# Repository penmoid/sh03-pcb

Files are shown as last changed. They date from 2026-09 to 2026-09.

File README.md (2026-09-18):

# SH03 controller

SH03 controller is an ESP32-S3-DevKitC-1 carrier board for the Sovol SH03
filament dryer. The board is a two-layer, 100 × 56 mm design. It carries nine
back-side SMD references: J1, J2, R1-R4, and C1-C3. J3 and the DevKitC-1
headers are through-hole parts fitted by the builder.

This repository contains the KiCad source, custom footprints, schematic
exports, fabrication files, renders, validation reports, and regeneration
scripts. The current design is Rev-A.

## Validation status

The repository documents CAD, DRC/ERC, routing, placement, and fabrication
checks. The project author has personally validated correct operation of the
assembled Rev-A board in the dryer. Perform the checks in
[docs/bring-up.md](docs/bring-up.md) before connecting a board to a dryer.

No firmware is included. The GPIO assignments are documented in
[docs/gpio-remap.md](docs/gpio-remap.md).

## Fabrication

The upload package is in [fab/](fab/). Read [fab/README.md](fab/README.md)
before ordering. The package contains Gerbers, a BOM, a CPL, and a STEP
export.

The BOM and sourcing notes are in [docs/bom.md](docs/bom.md). Connector mate
compatibility and all order-time sourcing information require confirmation
before an order.

## Images

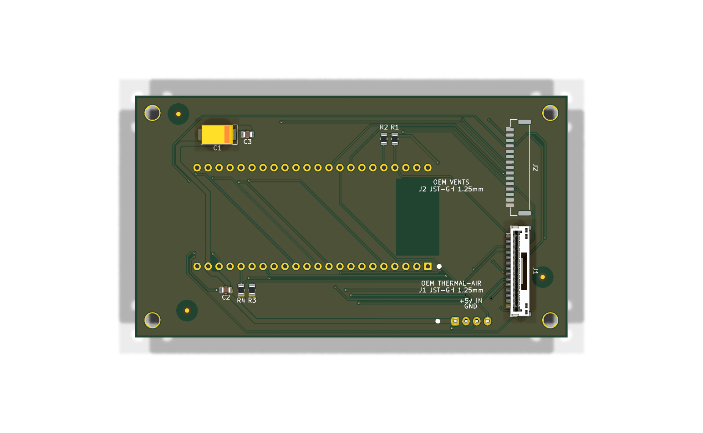
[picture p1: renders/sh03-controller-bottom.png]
Bottom render

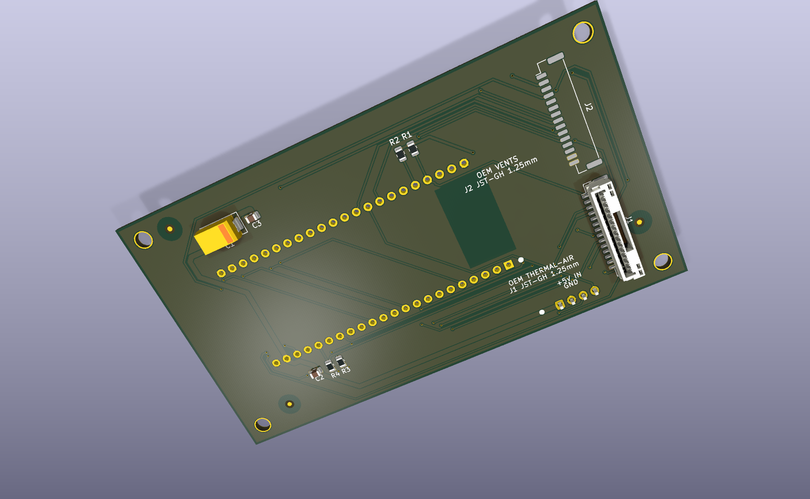
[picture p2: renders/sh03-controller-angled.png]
Angled render, J2 3D model unavailable


The angled render does not include a resolved J2 3D model.

## Toolchain

The source was generated and checked with KiCad 10.0.5. The scripts use the
standalone `pcbnew` Python module. The fab guide includes the `kicad-cli`
commands for Gerbers, drills, CPL, SVG, 3D renders, and schematic PDF export.

The board generation pipeline is documented in
[docs/layout-plan.md](docs/layout-plan.md):

```text
scripts/place_footprints.py
scripts/route_board.py
scripts/add_ground_pour.py
scripts/add_fiducials.py
```

Run `scripts/check_placement.py`, `scripts/report_pads.py`, and
`scripts/check_determinism.py` after regeneration.

## Licensing

Hardware and documentation are covered by [CERN-OHL-P-2.0](LICENSE).
Scripts are covered by [MIT](LICENSES/MIT.txt). See [NOTICE.md](NOTICE.md) for
third-party and KiCad-derived footprint exceptions.

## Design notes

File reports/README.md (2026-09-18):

# CAD validation

KiCad CLI 10.0.5 checked the unchanged Rev-A PCB and schematic on
2026-09-18. The project symbol library resolves through `${KIPRJMOD}`.

| Check | Errors | Warnings | Unconnected items |
|---|---:|---:|---:|
| DRC | 0 | 4 | 0 |
| ERC | 0 | 1 | Not applicable |

The four DRC warnings concern the local H1-H4 mounting-hole footprints, which
are absent from the configured `MountingHole` library. The ERC warning is a
U1 library-symbol mismatch: the embedded symbol hides pin numbers and uses
`~` for the datasheet field, while the library copy does not hide the numbers
and leaves that field empty. All 44 pin definitions match, including numbers,
names, electrical types, positions, and lengths.

The reports include all severities and no excluded violations. The existing
project configuration ignores these checks:

- DRC: missing courtyard, track endpoint not centered on via, tuning profile
  geometry, footprint filter mismatch, and footprint type mismatch.
- ERC: single-use global label, four-way junction, SPICE model issue, and
  footprint filter mismatch.

Run these commands from the project root with KiCad 10.0.5:

```sh
kicad-cli pcb drc --format json --severity-all -o reports/drc.json sh03-controller.kicad_pcb
kicad-cli sch erc --format json --severity-all -o reports/erc.json sh03-controller.kicad_sch
```

The Gerber outline matches the board at 100 × 56 mm. All nine BOM/CPL
references match the board, including placement coordinates and rotations
with the exported Y-axis sign convention. C1 pad 1 connects to +5V and pad 2
to GND.

These reports cover CAD checks. The project author has also personally validated
correct operation of the assembled Rev-A board in the dryer.

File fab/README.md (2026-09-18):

# Fabrication package

This directory contains the Rev-A order package generated from
`sh03-controller.kicad_pcb` with KiCad 10.0.5:

| File | Contents |
|---|---|
| `sh03-controller-gerbers.zip` | Gerbers, Excellon drill, and job file |
| `sh03-controller-cpl.csv` | Nine back-side SMD placements |
| `sh03-controller-bom.csv` | BOM covering nine SMD references |
| `sh03-controller.step` | Board and available 3D models |

The committed archive is the first-order package and remains unchanged for
reference. It uses a merged drill file. The fabrication house finished the
four mounting holes as plated 3.2 mm holes on that order. A future export should use
`--excellon-separate-th` and must be reviewed as a new package because that
flag changes the drill outputs.

## Assembly

All nine SMD references are on B.Cu: J1, J2, R1-R4, and C1-C3. J3 and U1's
2×22, 2.54 mm header arrangement are through-hole work. Direct soldering U1
is also supported.

Before ordering, confirm the JLCPCB Assembly Viewer orientation:

- J2, the 15-position vents connector, is in the north slot.
- J1, the 14-position thermal and air connector, is in the south slot.
- Both connectors are back-side placements with CPL rotation 270°.
- C1's positive stripe is on the +5V side.

The first order required a +180° correction in the Assembly Viewer for J1 and
J2. The correction was made in the viewer and was not silently applied to the
CPL. Review the native 270° CPL values and make any assembly-house correction
explicit during order review.

The committed STEP export does not contain a resolved J2 3D model. Use the
footprint and datasheet dimensions for J2 mechanical checks.

## Gerbers and drill

Run these commands from the project root. Create output directories first.

```text
mkdir -p build/gerbers

kicad-cli pcb export gerbers -o build/gerbers \
  -l F.Cu,B.Cu,F.SilkS,B.SilkS,F.Mask,B.Mask,F.Paste,B.Paste,Edge.Cuts \
  --no-x2 --no-netlist sh03-controller.kicad_pcb

kicad-cli pcb export drill -o build/gerbers/ --format excellon \
  --drill-origin absolute -u mm --excellon-zeros-format decimal \
  --generate-map --map-format gerberx2 sh03-controller.kicad_pcb
```

The merged drill export may cause the fabrication CAM process to treat NPTH
mounting holes as plated. Choose either the merged drill set or a separate
PTH/NPTH drill set for an upload. Never include both drill sets in one upload.
Use this command for a future separate export, then inspect the replacement
package:

```text
mkdir -p build/drill-separated

kicad-cli pcb export drill -o build/drill-separated/ --format excellon \
  --drill-origin absolute -u mm --excellon-zeros-format decimal \
  --excellon-separate-th --generate-map --map-format gerberx2 \
  sh03-controller.kicad_pcb
```

Generate a drill report when reviewing a package:

```text
kicad-cli pcb export drill -o build/gerbers/ --format excellon \
  --drill-origin absolute -u mm --excellon-zeros-format decimal \
  --generate-report --report-path build/gerbers/drill-report.txt \
  sh03-controller.kicad_pcb
```

The Gerber and CPL coordinate origin is the board file origin. Gerber and CPL
Y coordinates use the opposite sign from KiCad page coordinates.

## CPL

Export the placement list with:

```text
kicad-cli pcb export pos -o build/gerbers/sh03-controller-back-pos.csv \
  --side back --format csv --units mm sh03-controller.kicad_pcb
```

Filter the output to `J1`, `J2`, `R1`, `R2`, `R3`, `R4`, `C1`, `C2`, and `C3`.
Use the JLCPCB headers `Designator,Mid X,Mid Y,Layer,Rotation`, normalize
negative rotations into the 0 to 360 range, and keep all nine rows on the
bottom layer. Do not apply an undocumented connector rotation offset.

## SVG and 3D exports

These commands use the project root as the working directory. Run them with
KiCad 10.0.5 and the KiCad 3D model data available to the renderer.

```text
mkdir -p build/svg renders

kicad-cli pcb export svg -o build/svg/top-2d.svg \
  --layers F.Cu,F.SilkS,F.Mask,F.Paste,Edge.Cuts --page-size-mode 2 \
  --exclude-drawing-sheet --mode-single sh03-controller.kicad_pcb

kicad-cli pcb export svg -o build/svg/bottom-2d.svg \
  --layers B.Cu,B.SilkS,B.Mask,B.Paste,Edge.Cuts --page-size-mode 2 \
  --exclude-drawing-sheet --mode-single --mirror sh03-controller.kicad_pcb

kicad-cli pcb render -o renders/sh03-controller-top.png --side top \
  --width 1568 --height 984 --quality high --floor sh03-controller.kicad_pcb

kicad-cli pcb render -o renders/sh03-controller-bottom.png --side bottom \
  --width 1568 --height 984 --quality high --floor sh03-controller.kicad_pcb

kicad-cli pcb render -o renders/sh03-controller-angled.png --side bottom \
  --width 1568 --height 984 --quality high --perspective \
  --rotate 20,0,-25 --zoom 1.0 --background opaque sh03-controller.kicad_pcb

kicad-cli pcb render -o renders/sh03-controller-top-2d.png --side top \
  --width 1568 --height 984 --quality basic sh03-controller.kicad_pcb

kicad-cli pcb render -o renders/sh03-controller-bottom-2d.png --side bottom \
  --width 1568 --height 984 --quality basic sh03-controller.kicad_pcb
```

Export the schematic PDF separately:

```text
kicad-cli sch export pdf -o renders/sh03-controller-schematic.pdf \
  sh03-controller.kicad_sch
```

## Validation

The tracked reports record KiCad DRC and ERC runs. See
[`reports/README.md`](../reports/README.md). DRC reports 0 errors and 0
unconnected items with four mounting-hole library warnings. ERC reports one
U1 library-symbol warning. The 44 U1 pins are equivalent; the warning concerns
symbol display and metadata.

The project author has personally validated correct operation of the assembled
Rev-A board in the dryer.

Before releasing an order, inspect the Gerber viewer, drill map, BOM/CPL
reference alignment, C1 polarity, J1/J2 placement, and the J2 no-connect pin.

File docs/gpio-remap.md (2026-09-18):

# GPIO map

This table is the current PCB map. It includes the Hall ADC1 correction. Use
it for firmware written for the PCB.

| Signal | PCB GPIO | ADC or function |
|---|---:|---|
| TH2 | 1 | ADC1 |
| TH1 | 2 | ADC1 |
| MC_HOT2 | 11 | Digital |
| MC_HOT1 | 12 | Digital |
| MC_K_FAN3_FG | 38 | Tacho input |
| MC_K_FAN3 | 21 | Digital |
| MC_K_FAN2_FG | 48 | Tacho input |
| MC_K_FAN2 | 14 | Digital |
| MC_K_FAN1_FG | 47 | Tacho input |
| MC_K_FAN1 | 13 | Digital |
| MC_HUM_SDA | 8 | I2C |
| MC_HUM_SCL | 9 | I2C |
| MC_HALLA | 4 | ADC1_CH3 |
| MC_HALLB | 10 | ADC1_CH9 |
| MC_HALLC | 7 | ADC1_CH6 |
| MC_HALLD | 6 | ADC1_CH5 |
| MC_XQA1 | 41 | Digital |
| MC_XQA2 | 40 | Digital |
| MC_XQB1 | 3 | Digital, strapping pin |
| MC_XQB2 | 18 | Digital |
| MC_XQC1 | 15 | Digital |
| MC_XQC2 | 17 | Digital |
| MC_XQD1 | 5 | Digital |
| MC_XQD2 | 42 | Digital |
| MCU_TX | 16 | UART |
| MCU_RX | 39 | UART |

TH2 uses ADC1 GPIO1. TH1 uses ADC1 GPIO2. The UART is GPIO16/GPIO39. USB and
UART0 GPIO43/GPIO44 are unused by the board. The Hall sensors are ratiometric
analog inputs, so all four must stay on ADC1 GPIO1 through GPIO10 when WiFi is
active. GPIO11 through GPIO20 use ADC2 and are unsuitable for these inputs in
that condition. GPIO42 has no ADC channel.

## Perfboard to PCB changes

The current PCB changes these ten signal assignments from the earlier
perfboard wiring:

| Signal | Perfboard GPIO | PCB GPIO |
|---|---:|---:|
| MC_HALLB | 5 | 10 |
| MC_HALLC | 6 | 7 |
| MC_HALLD | 7 | 6 |
| MC_XQA1 | 17 | 41 |
| MC_XQA2 | 15 | 40 |
| MC_XQB1 | 10 | 3 |
| MC_XQC1 | 3 | 15 |
| MC_XQC2 | 40 | 17 |
| MC_XQD1 | 42 | 5 |
| MC_XQD2 | 41 | 42 |

MC_HALLA remains on GPIO4. MC_XQB2 remains on GPIO18. The TH, HOT, fan,
tacho, I2C, and UART assignments are listed in the authoritative table above.

## Firmware cutover

The repository contains no firmware. Keep the existing device on its old map
until the PCB has passed the bring-up checks and is ready for cutover. Apply
the current table only to firmware running with this PCB. A firmware update on
the earlier wiring changes the vent and Hall signals.

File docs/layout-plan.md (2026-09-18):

# Rev-A layout

This document describes the current board geometry and the constraints used by
the placement and routing scripts. Dimensions are millimetres.

## Enclosure and board

| Feature | Dimension or location |
|---|---|
| Enclosure cavity | 135.2 × 82.2 |
| Cable window | X 21.5 to 33.5, Y 15.5 to 66.7 |
| Board outline | 100 × 56, KiCad X 36 to 136 and Y 33 to 89 |
| Mounting holes | Four 3.2 mm finished holes, approximately 4 mm from board corners |

The board clears the enclosure bosses within the cavity Y band 10.5 to 71.6.
J1 and J2 sit in the cable window on the back side. J2 is the 15-position
connector in the north slot. J1 is the 14-position connector in the south slot.
Both connectors have pin 1 at the north end of their span.

## Placement

| Ref | Side | KiCad centre | Rotation | Function |
|---|---|---:|---:|---|
| J2 | B.Cu | (47.4, 49.625) | 270° | 15-position vents connector |
| J1 | B.Cu | (47.4, 73.625) | 270° | 14-position thermal and air connector |
| R1 | B.Cu | (75.95, 43.0) | 270° | TH2 33k pull-up |
| R2 | B.Cu | (78.49, 43.0) | 270° | TH1 33k pull-up |
| R3 | B.Cu | (108.97, 78.0) | 270° | MC_HOT2 10k pull-down |
| R4 | B.Cu | (111.51, 78.0) | 270° | MC_HOT1 10k pull-down |
| C1 | B.Cu | (117.0, 42.0) | 0° | 470 µF +5V bulk capacitor |
| C3 | B.Cu | (110.0, 42.0) | 0° | 10 µF +5V bypass |
| C2 | B.Cu | (115.0, 78.0) | 0° | 100 nF near J3 |
| U1 | F.Cu | (95.0, 61.1) | 90° | ESP32-S3-DevKitC-1 |
| J3 | F.Cu | (62.0, 85.2) | 180° | 4-position XH connector |

U1 is the height driver at about 7.2 mm above the PCB. J1 and J2 are about
4.25 mm high. C1 is about 4.3 mm high. Trim header tails flush after fitting
U1.

The four Hall signals use U1 GPIO4, GPIO6, GPIO7, and GPIO10. These are ADC1
inputs and remain usable while WiFi is active. See
[docs/gpio-remap.md](gpio-remap.md).

J2 pin 13 is no-connect by design. It isolates the driver-board 3V3 signal.
R3 and R4 provide the heater pull-downs and must be present.

## Reproduction

The source of truth for placement is the `PLACEMENT` dictionary in
`scripts/place_footprints.py`. The regeneration order is:

```text
mkdir -p build
kicad-cli sch export netlist --format kicadxml -o build/sh03.net \
  sh03-controller.kicad_sch
python3 scripts/place_footprints.py
python3 scripts/route_board.py
python3 scripts/add_ground_pour.py
python3 scripts/add_fiducials.py
```

Run these checks after regeneration:

```text
python3 scripts/check_placement.py
python3 scripts/report_pads.py
python3 scripts/check_determinism.py
```

`check_placement.py` checks courtyard overlap, board-edge clearance, requested
connector-hole clearances, and antenna keepout. `report_pads.py` reports the
connector and U1 pad mapping. `check_determinism.py` runs the pipeline twice
and compares the resulting board files.

The scripts use KiCad 10.0.5's standalone `pcbnew` Python module. They resolve
the project footprint libraries through the local library tables. Run the
pipeline on a disposable copy because the generation scripts overwrite the
board and generated pad reports.

For a Linux host with KiCad 10.0.5 installed, run the commands above from the
project root. To use the KiCad container, check the version and bind-mount the
project directory:

```text
docker run --rm -v "$PWD:/work" -w /work kicad/kicad:10.0 \
  kicad-cli --version
```

The current project was checked with KiCad 10.0.5. The container image may
resolve to a different 10.0 release, so confirm the version before generating
files. The base image does not provide every 3D model package. Install or
mount the KiCad 3D model data separately before rendering.

The fab guide contains the complete `kicad-cli` export commands. The committed
STEP export has no resolved J2 3D model. Treat its J2 visualization as
incomplete and check the physical part dimensions against the footprint.

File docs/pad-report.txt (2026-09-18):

ref    pin    net                     pad_x_mm  pad_y_mm  pad_w_mm  pad_h_mm shape      type layer   drill_mm
-------------------------------------------------------------------------------------------------------------
C1     1      /+5V                     113.793    42.000     2.245     2.590 roundrect  SMD  B.Cu            
C1     2      /GND                     120.207    42.000     2.245     2.590 roundrect  SMD  B.Cu            
C2     1      /+5V                     114.050    78.000     1.000     1.450 roundrect  SMD  B.Cu            
C2     2      /GND                     115.950    78.000     1.000     1.450 roundrect  SMD  B.Cu            
C3     1      /+5V                     109.050    42.000     1.000     1.450 roundrect  SMD  B.Cu            
C3     2      /GND                     110.950    42.000     1.000     1.450 roundrect  SMD  B.Cu            
H1            <no net>                  40.000    37.000     3.700     3.700 circle     TH   *          3.200
H2            <no net>                 128.000    37.000     3.700     3.700 circle     TH   *          3.200
H3            <no net>                  40.000    85.000     3.700     3.700 circle     TH   *          3.200
H4            <no net>                 128.000    85.000     3.700     3.700 circle     TH   *          3.200
J1     1      /TH2                      49.350    65.500     0.700     1.800 roundrect  SMD  B.Cu            
J1     2      /TH1                      49.350    66.750     0.700     1.800 roundrect  SMD  B.Cu            
J1     3      /MC_HOT2                  49.350    68.000     0.700     1.800 roundrect  SMD  B.Cu            
J1     4      /MC_HOT1                  49.350    69.250     0.700     1.800 roundrect  SMD  B.Cu            
J1     5      /MC_K_FAN3_FG             49.350    70.500     0.700     1.800 roundrect  SMD  B.Cu            
J1     6      /MC_K_FAN3                49.350    71.750     0.700     1.800 roundrect  SMD  B.Cu            
J1     7      /MC_K_FAN2_FG             49.350    73.000     0.700     1.800 roundrect  SMD  B.Cu            
J1     8      /MC_K_FAN2                49.350    74.250     0.700     1.800 roundrect  SMD  B.Cu            
J1     9      /MC_K_FAN1_FG             49.350    75.500     0.700     1.800 roundrect  SMD  B.Cu            
J1     10     /MC_K_FAN1                49.350    76.750     0.700     1.800 roundrect  SMD  B.Cu            
J1     11     /MC_HUM_SDA               49.350    78.000     0.700     1.800 roundrect  SMD  B.Cu            
J1     12     /MC_HUM_SCL               49.350    79.250     0.700     1.800 roundrect  SMD  B.Cu            
J1     13     /+5V                      49.350    80.500     0.700     1.800 roundrect  SMD  B.Cu            
J1     14     /GND                      49.350    81.750     0.700     1.800 roundrect  SMD  B.Cu            
J1     MP     <no net>                  45.930    63.660     1.020     2.940 roundrect  SMD  B.Cu            
J1     MP     <no net>                  45.930    83.590     1.020     2.940 roundrect  SMD  B.Cu            
J2     1      /MC_XQD2                  49.350    40.875     0.700     1.800 roundrect  SMD  B.Cu            
J2     2      /MC_XQD1                  49.350    42.125     0.700     1.800 roundrect  SMD  B.Cu            
J2     3      /MC_HALLD                 49.350    43.375     0.700     1.800 roundrect  SMD  B.Cu            
J2     4      /MC_XQC2                  49.350    44.625     0.700     1.800 roundrect  SMD  B.Cu            
J2     5      /MC_XQC1                  49.350    45.875     0.700     1.800 roundrect  SMD  B.Cu            
J2     6      /MC_HALLC                 49.350    47.125     0.700     1.800 roundrect  SMD  B.Cu            
J2     7      /MC_XQB2                  49.350    48.375     0.700     1.800 roundrect  SMD  B.Cu            
J2     8      /MC_XQB1                  49.350    49.625     0.700     1.800 roundrect  SMD  B.Cu            
J2     9      /MC_HALLB                 49.350    50.875     0.700     1.800 roundrect  SMD  B.Cu            
J2     10     /MC_XQA2                  49.350    52.125     0.700     1.800 roundrect  SMD  B.Cu            
J2     11     /MC_XQA1                  49.350    53.375     0.700     1.800 roundrect  SMD  B.Cu            
J2     12     /MC_HALLA                 49.350    54.625     0.700     1.800 roundrect  SMD  B.Cu            
J2     13     unconnected-(J2-Pin_13-Pad13)    49.350    55.875     0.700     1.800 roundrect  SMD  B.Cu            
J2     14     /GND                      49.350    57.125     0.700     1.800 roundrect  SMD  B.Cu            
J2     15     /GND                      49.350    58.375     0.700     1.800 roundrect  SMD  B.Cu            
J2     MP     <no net>                  45.930    39.035     1.020     2.940 roundrect  SMD  B.Cu            
J2     MP     <no net>                  45.930    60.215     1.020     2.940 roundrect  SMD  B.Cu            
J3     1      /+5V                      62.000    85.200     1.700     1.950 roundrect  TH   *          0.950
J3     2      /GND                      59.500    85.200     1.700     1.950 oval       TH   *          0.950
J3     3      /MCU_TX                   57.000    85.200     1.700     1.950 oval       TH   *          0.950
J3     4      /MCU_RX                   54.500    85.200     1.700     1.950 oval       TH   *          0.950
R1     1      /+3V3                     75.950    42.087     1.025     1.400 roundrect  SMD  B.Cu            
R1     2      /TH2                      75.950    43.913     1.025     1.400 roundrect  SMD  B.Cu            
R2     1      /+3V3                     78.490    42.087     1.025     1.400 roundrect  SMD  B.Cu            
R2     2      /TH1                      78.490    43.913     1.025     1.400 roundrect  SMD  B.Cu            
R3     1      /MC_HOT2                 108.970    77.088     1.025     1.400 roundrect  SMD  B.Cu            
R3     2      /GND                     108.970    78.912     1.025     1.400 roundrect  SMD  B.Cu            
R4     1      /MC_HOT1                 111.510    77.088     1.025     1.400 roundrect  SMD  B.Cu            
R4     2      /GND                     111.510    78.912     1.025     1.400 roundrect  SMD  B.Cu            
U1     1      /+3V3                     68.330    72.530     1.700     1.700 rect       TH   *          1.000
U1     2      /+3V3                     70.870    72.530     1.700     1.700 circle     TH   *          1.000
U1     3      unconnected-(U1-RST-Pad3)    73.410    72.530     1.700     1.700 circle     TH   *          1.000
U1     4      /MC_HALLA                 75.950    72.530     1.700     1.700 circle     TH   *          1.000
U1     5      /MC_XQD1                  78.490    72.530     1.700     1.700 circle     TH   *          1.000
U1     6      /MC_HALLD                 81.030    72.530     1.700     1.700 circle     TH   *          1.000
U1     7      /MC_HALLC                 83.570    72.530     1.700     1.700 circle     TH   *          1.000
U1     8      /MC_XQC1                  86.110    72.530     1.700     1.700 circle     TH   *          1.000
U1     9      /MCU_TX                   88.650    72.530     1.700     1.700 circle     TH   *          1.000
U1     10     /MC_XQC2                  91.190    72.530     1.700     1.700 circle     TH   *          1.000
U1     11     /MC_XQB2                  93.730    72.530     1.700     1.700 circle     TH   *          1.000
U1     12     /MC_HUM_SDA               96.270    72.530     1.700     1.700 circle     TH   *          1.000
U1     13     /MC_XQB1                  98.810    72.530     1.700     1.700 circle     TH   *          1.000
U1     14     unconnected-(U1-GPIO46-Pad14)   101.350    72.530     1.700     1.700 circle     TH   *          1.000
U1     15     /MC_HUM_SCL              103.890    72.530     1.700     1.700 circle     TH   *          1.000
U1     16     /MC_HALLB                106.430    72.530     1.700     1.700 circle     TH   *          1.000
U1     17     /MC_HOT2                 108.970    72.530     1.700     1.700 circle     TH   *          1.000
U1     18     /MC_HOT1                 111.510    72.530     1.700     1.700 circle     TH   *          1.000
U1     19     /MC_K_FAN1               114.050    72.530     1.700     1.700 circle     TH   *          1.000
U1     20     /MC_K_FAN2               116.590    72.530     1.700     1.700 circle     TH   *          1.000
U1     21     /+5V                     119.130    72.530     1.700     1.700 circle     TH   *          1.000
U1     22     /GND                     121.670    72.530     1.700     1.700 circle     TH   *          1.000
U1     23     /GND                      68.330    49.670     1.700     1.700 circle     TH   *          1.000
U1     24     unconnected-(U1-TX_GPIO43-Pad24)    70.870    49.670     1.700     1.700 circle     TH   *          1.000
U1     25     unconnected-(U1-RX_GPIO44-Pad25)    73.410    49.670     1.700     1.700 circle     TH   *          1.000
U1     26     /TH2                      75.950    49.670     1.700     1.700 circle     TH   *          1.000
U1     27     /TH1                      78.490    49.670     1.700     1.700 circle     TH   *          1.000
U1     28     /MC_XQD2                  81.030    49.670     1.700     1.700 circle     TH   *          1.000
U1     29     /MC_XQA1                  83.570    49.670     1.700     1.700 circle     TH   *          1.000
U1     30     /MC_XQA2                  86.110    49.670     1.700     1.700 circle     TH   *          1.000
U1     31     /MCU_RX                   88.650    49.670     1.700     1.700 circle     TH   *          1.000
U1     32     /MC_K_FAN3_FG             91.190    49.670     1.700     1.700 circle     TH   *          1.000
U1     33     unconnected-(U1-GPIO37-Pad33)    93.730    49.670     1.700     1.700 circle     TH   *          1.000
U1     34     unconnected-(U1-GPIO36-Pad34)    96.270    49.670     1.700     1.700 circle     TH   *          1.000
U1     35     unconnected-(U1-GPIO35-Pad35)    98.810    49.670     1.700     1.700 circle     TH   *          1.000
U1     36     unconnected-(U1-GPIO0-Pad36)   101.350    49.670     1.700     1.700 circle     TH   *          1.000
U1     37     unconnected-(U1-GPIO45-Pad37)   103.890    49.670     1.700     1.700 circle     TH   *          1.000
U1     38     /MC_K_FAN2_FG            106.430    49.670     1.700     1.700 circle     TH   *          1.000
U1     39     /MC_K_FAN1_FG            108.970    49.670     1.700     1.700 circle     TH   *          1.000
U1     40     /MC_K_FAN3               111.510    49.670     1.700     1.700 circle     TH   *          1.000
U1     41     unconnected-(U1-GPIO20-Pad41)   114.050    49.670     1.700     1.700 circle     TH   *          1.000
U1     42     unconnected-(U1-GPIO19-Pad42)   116.590    49.670     1.700     1.700 circle     TH   *          1.000
U1     43     /GND                     119.130    49.670     1.700     1.700 circle     TH   *          1.000
U1     44     /GND                     121.670    49.670     1.700     1.700 circle     TH   *          1.000

=== Summary 1: nets with more than one pad ===
/+3V3: R1.1 (75.950, 42.087) -> R2.1 (78.490, 42.087) -> U1.1 (68.330, 72.530) -> U1.2 (70.870, 72.530)
/+5V: C1.1 (113.793, 42.000) -> C2.1 (114.050, 78.000) -> C3.1 (109.050, 42.000) -> J1.13 (49.350, 80.500) -> J3.1 (62.000, 85.200) -> U1.21 (119.130, 72.530)
/GND: C1.2 (120.207, 42.000) -> C2.2 (115.950, 78.000) -> C3.2 (110.950, 42.000) -> J1.14 (49.350, 81.750) -> J2.14 (49.350, 57.125) -> J2.15 (49.350, 58.375) -> J3.2 (59.500, 85.200) -> R3.2 (108.970, 78.912) -> R4.2 (111.510, 78.912) -> U1.22 (121.670, 72.530) -> U1.23 (68.330, 49.670) -> U1.43 (119.130, 49.670) -> U1.44 (121.670, 49.670)
/MCU_RX: J3.4 (54.500, 85.200) -> U1.31 (88.650, 49.670)
/MCU_TX: J3.3 (57.000, 85.200) -> U1.9 (88.650, 72.530)
/MC_HALLA: J2.12 (49.350, 54.625) -> U1.4 (75.950, 72.530)
/MC_HALLB: J2.9 (49.350, 50.875) -> U1.16 (106.430, 72.530)
/MC_HALLC: J2.6 (49.350, 47.125) -> U1.7 (83.570, 72.530)
/MC_HALLD: J2.3 (49.350, 43.375) -> U1.6 (81.030, 72.530)
/MC_HOT1: J1.4 (49.350, 69.250) -> R4.1 (111.510, 77.088) -> U1.18 (111.510, 72.530)
/MC_HOT2: J1.3 (49.350, 68.000) -> R3.1 (108.970, 77.088) -> U1.17 (108.970, 72.530)
/MC_HUM_SCL: J1.12 (49.350, 79.250) -> U1.15 (103.890, 72.530)
/MC_HUM_SDA: J1.11 (49.350, 78.000) -> U1.12 (96.270, 72.530)
/MC_K_FAN1: J1.10 (49.350, 76.750) -> U1.19 (114.050, 72.530)
/MC_K_FAN1_FG: J1.9 (49.350, 75.500) -> U1.39 (108.970, 49.670)
/MC_K_FAN2: J1.8 (49.350, 74.250) -> U1.20 (116.590, 72.530)
/MC_K_FAN2_FG: J1.7 (49.350, 73.000) -> U1.38 (106.430, 49.670)
/MC_K_FAN3: J1.6 (49.350, 71.750) -> U1.40 (111.510, 49.670)
/MC_K_FAN3_FG: J1.5 (49.350, 70.500) -> U1.32 (91.190, 49.670)
/MC_XQA1: J2.11 (49.350, 53.375) -> U1.29 (83.570, 49.670)
/MC_XQA2: J2.10 (49.350, 52.125) -> U1.30 (86.110, 49.670)
/MC_XQB1: J2.8 (49.350, 49.625) -> U1.13 (98.810, 72.530)
/MC_XQB2: J2.7 (49.350, 48.375) -> U1.11 (93.730, 72.530)
/MC_XQC1: J2.5 (49.350, 45.875) -> U1.8 (86.110, 72.530)
/MC_XQC2: J2.4 (49.350, 44.625) -> U1.10 (91.190, 72.530)
/MC_XQD1: J2.2 (49.350, 42.125) -> U1.5 (78.490, 72.530)
/MC_XQD2: J2.1 (49.350, 40.875) -> U1.28 (81.030, 49.670)
/TH1: J1.2 (49.350, 66.750) -> R2.2 (78.490, 43.913) -> U1.27 (78.490, 49.670)
/TH2: J1.1 (49.350, 65.500) -> R1.2 (75.950, 43.913) -> U1.26 (75.950, 49.670)

Single-pad nets: unconnected-(J2-Pin_13-Pad13), unconnected-(U1-GPIO0-Pad36), unconnected-(U1-GPIO19-Pad42), unconnected-(U1-GPIO20-Pad41), unconnected-(U1-GPIO35-Pad35), unconnected-(U1-GPIO36-Pad34), unconnected-(U1-GPIO37-Pad33), unconnected-(U1-GPIO45-Pad37), unconnected-(U1-GPIO46-Pad14), unconnected-(U1-RST-Pad3), unconnected-(U1-RX_GPIO44-Pad25), unconnected-(U1-TX_GPIO43-Pad24)
Pads with no net assigned (not a net -- not electrically joined to each other): H1. (40.000, 37.000), H2. (128.000, 37.000), H3. (40.000, 85.000), H4. (128.000, 85.000), J1.MP (45.930, 63.660), J1.MP (45.930, 83.590), J2.MP (45.930, 39.035), J2.MP (45.930, 60.215)

=== Summary 2: U1 pad rows ===
row y=49.670mm: 22 pads, first x=68.330mm (U1.23), last x=121.670mm (U1.44), pitch(es)=[2.54]
row y=72.530mm: 22 pads, first x=68.330mm (U1.1), last x=121.670mm (U1.22), pitch(es)=[2.54]

=== Summary 3: open front-side routing channel between U1's pad rows ===
channel rectangle: x=[68.330, 121.670]mm, y=[50.520, 71.680]mm (height=21.160mm)
occupants already in that rectangle: (none -- channel is clear)

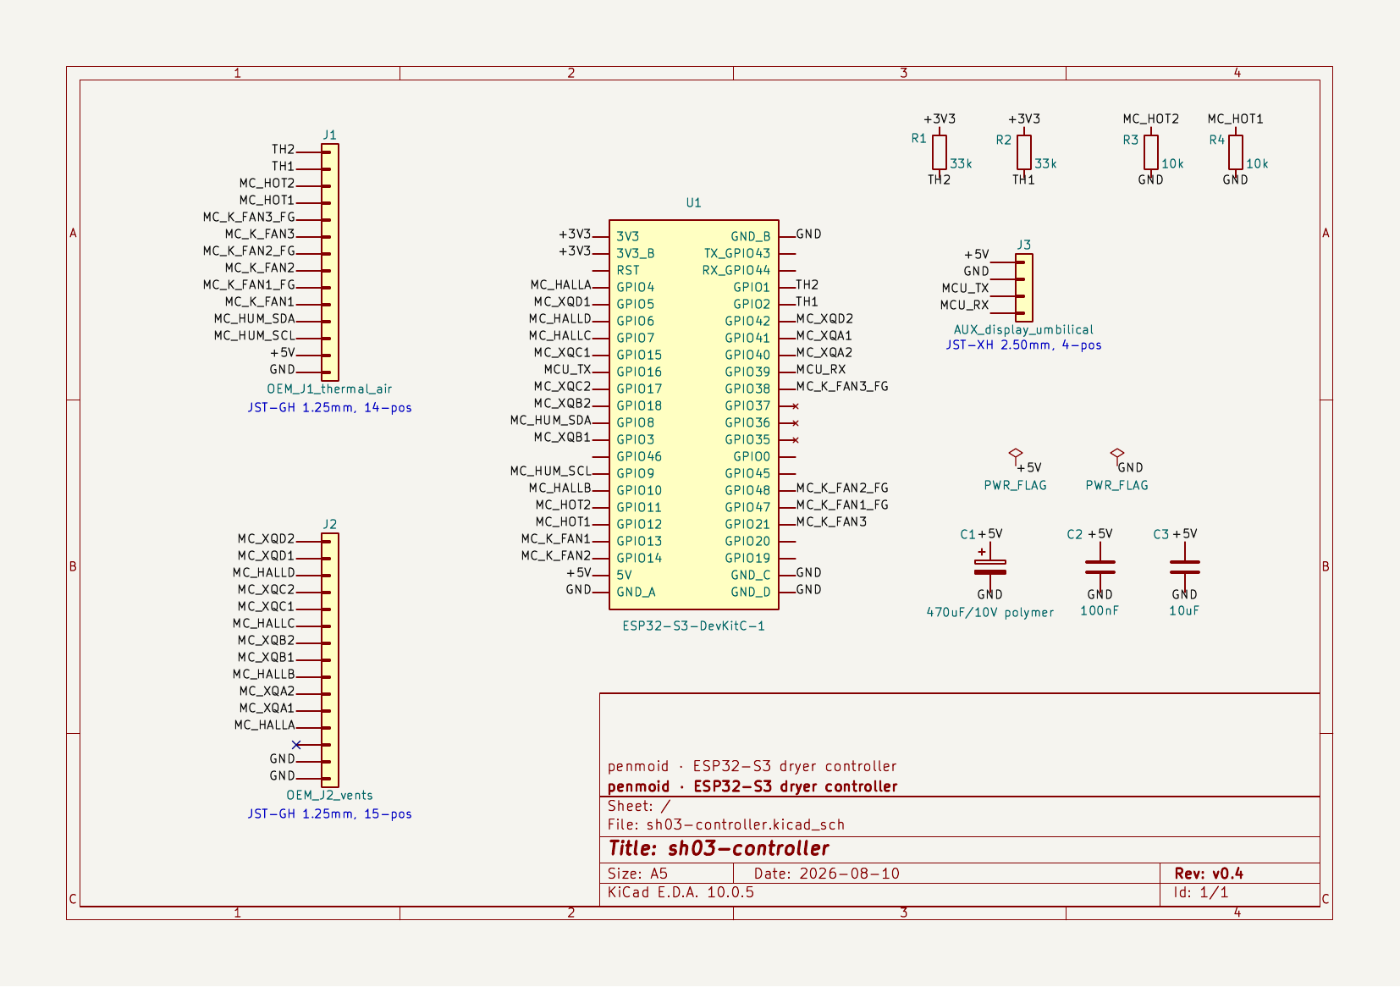
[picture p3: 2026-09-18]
renders/sh03-controller-schematic.png

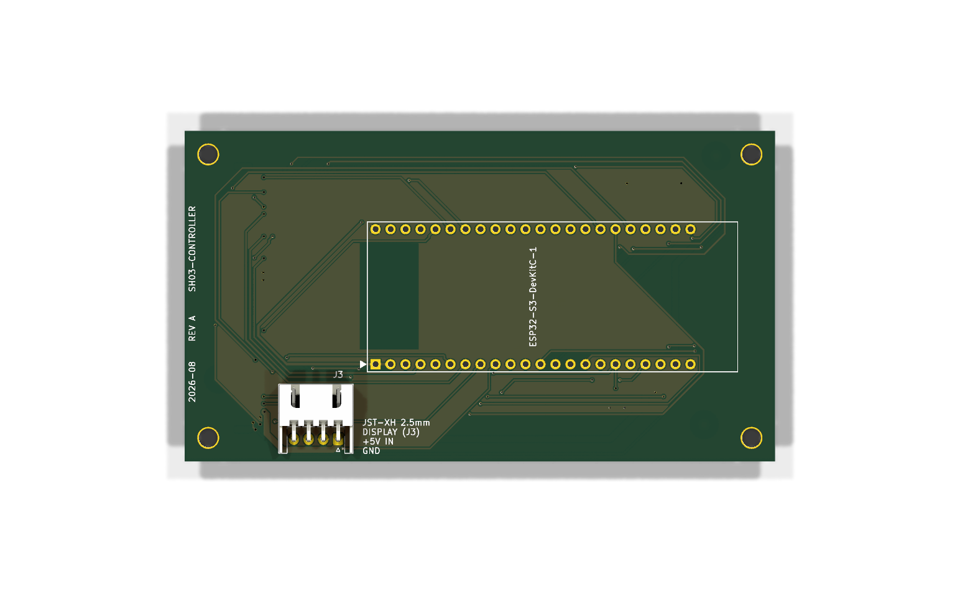
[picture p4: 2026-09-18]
renders/sh03-controller-top.png

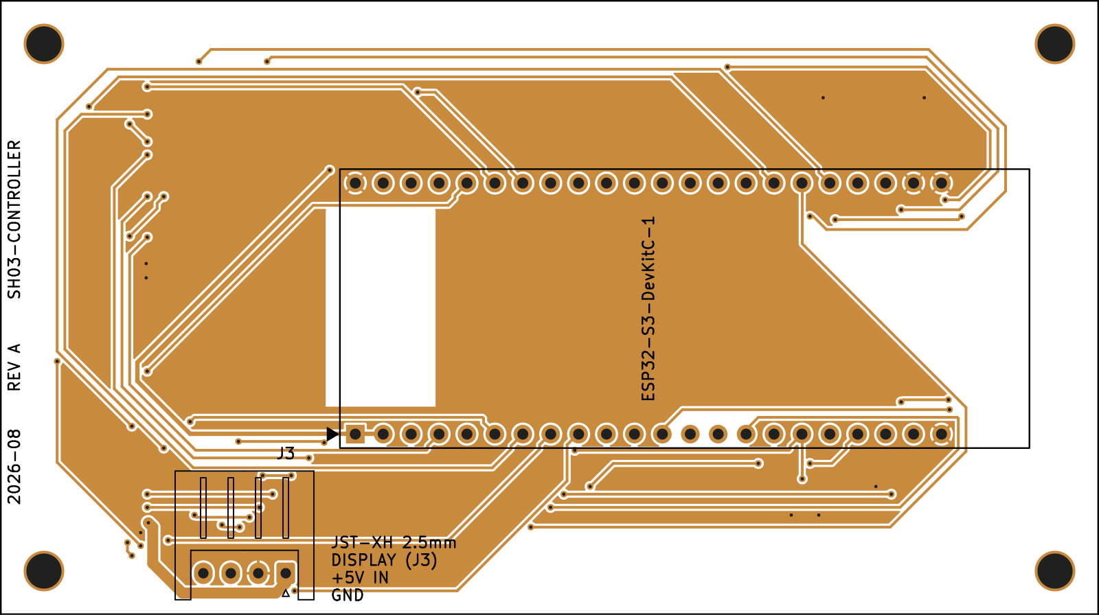
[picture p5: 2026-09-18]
renders/sh03-controller-top-layers.png

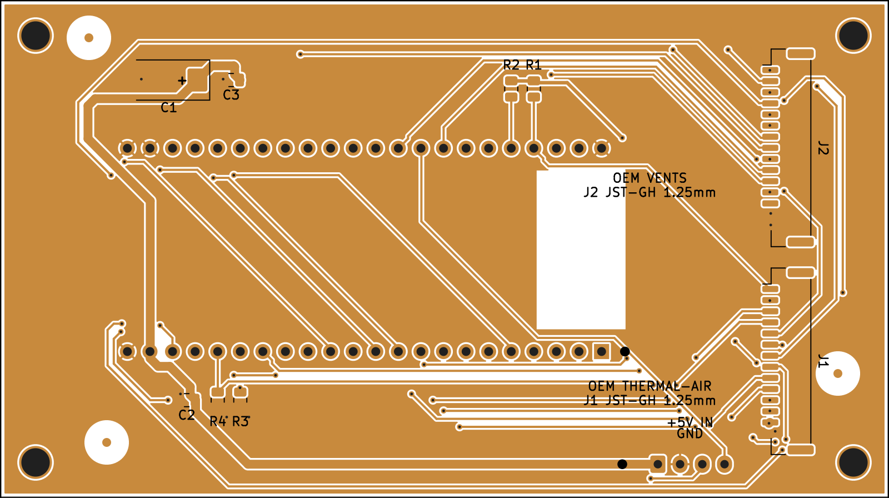
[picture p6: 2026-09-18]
renders/sh03-controller-bottom-layers.png

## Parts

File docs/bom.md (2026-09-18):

# Bill of materials

This file records the parts used by the Rev-A board and the alternatives that
must be checked before an order. Values and part numbers are design data.
Distributor stock, pricing, and assembly-library status change over time.

## SMD parts

| Ref | Value | Part | LCSC | Library |
|---|---|---|---|---|
| C1 | 470 µF, 10 V, MnO2 tantalum, EIA 7343-43 | Kyocera AVX TPSE477K010R0100 | `C444831` | Extended |
| R1, R2 | 33k, 0805, 1% | Uniroyal Elec 0805W8F3302T5E | `C17633` | Basic |
| R3, R4 | 10k, 0805, 1% | Uniroyal Elec 0805W8F1002T5E | `C17414` | Basic |
| C2 | 100nF, 50V, X7R, 0805 | YAGEO CC0805KRX7R9BB104 | `C49678` | Basic |
| C3 | 10uF, 25V, X5R, 0805 | Samsung Electro-Mechanics CL21A106KAYNNNE | `C15850` | Basic |

C1 is the 5 V rail bulk capacitor. The design uses a 10 V rating and a 50%
voltage derating target. The estimated 1 ms, 300 mA transient produces about
640 mV of capacitive droop at 470 µF and about 30 mV of ESR step at 100 mΩ.
The earlier candidate was KEMET T530X477M010A*E020. It is not used in Rev-A.

All nine SMD references are on B.Cu for single-side assembly: J1, J2, R1-R4,
and C1-C3. C1 is polarized. Confirm its positive marking in the assembly
viewer and on the assembled board.

## Connectors and through-hole parts

| Ref | Part | Notes |
|---|---|---|
| J1 | BM14B-GHS-TBT, or GH125-S14CCA-00 (`C2886792`) | 14-position GH connector |
| J2 | BM15B-GHS-TBT, or GH125-S15CCA-00 (`C2886793`) | 15-position GH connector |
| J3 | JST XH 4-position right-angle | Through-hole, fitted by the builder |
| U1 | ESP32-S3-DevKitC-1 | Suitable 2×22, 2.54 mm headers/socket arrangement, or direct solder |

J1's genuine JST part is BM14B-GHS-TBT (`C265384`). J2's genuine JST part is
BM15B-GHS-TBT. The JUSHUO GH125 parts are JLCPCB Extended-library options.
The custom footprints cover the pad envelopes for the genuine and clone parts.
The clone-to-genuine-housing mate was unverified when the order package was
prepared. A genuine JST connector has a reported fit with the genuine JST
housings. That report does not prove clone compatibility. Test each clone and
housing combination before an assembly run.

The cable-side housings are GHR-14V-S (`C566400`) and GHR-15V-S (`C594572`).
The GH crimp contact is SSHL-002T-P0.2. The cut-tape part is
`MINI-SSHL-002T-P0.2`. `SXH-001T-P0.6` is an XH-series contact and is not a
GH substitute.

A 14- or 15-position cable requires a matching cable assembly, loose contacts
and a housing, or a re-terminated OEM cable. The pre-crimped GH-to-GH
AGHGH28K152 assembly is an option to evaluate. Confirm its pin-to-pin
continuity before use.

## Electrical constraints

R3 and R4 are mandatory 10k heater pull-downs. Do not power the dryer through
this board with either resistor missing.

J2 pin 13 is intentionally no-connect. The driver-board 3V3 signal is isolated
on this revision. Do not populate or wire it as a 3V3 output.

The connector choice, cable construction, housing mate, and order-time
assembly-library availability remain order checks. This document does not
claim that any distributor inventory is current.

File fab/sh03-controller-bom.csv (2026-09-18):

Comment | Designator | Footprint | LCSC Part #
JUSHUO GH125-S14CCA-00 | J1 | JST_GH_BM14B_UNIVERSAL_1x14-1MP_P1.25mm_Vertical | C2886792
JUSHUO GH125-S15CCA-00 | J2 | JST_GH_BM15B_UNIVERSAL_1x15-1MP_P1.25mm_Vertical | C2886793
33k 0805 1% | R1 | R_0805_2012Metric | C17633
33k 0805 1% | R2 | R_0805_2012Metric | C17633
10k 0805 1% | R3 | R_0805_2012Metric | C17414
10k 0805 1% | R4 | R_0805_2012Metric | C17414
Kyocera AVX TPSE477K010R0100 470uF/10V tantalum | C1 | CP_EIA-7343-43_Kemet-X_HandSolder | C444831
100nF 50V X7R 0805 | C2 | C_0805_2012Metric | C49678
10uF 25V X5R 0805 | C3 | C_0805_2012Metric | C15850

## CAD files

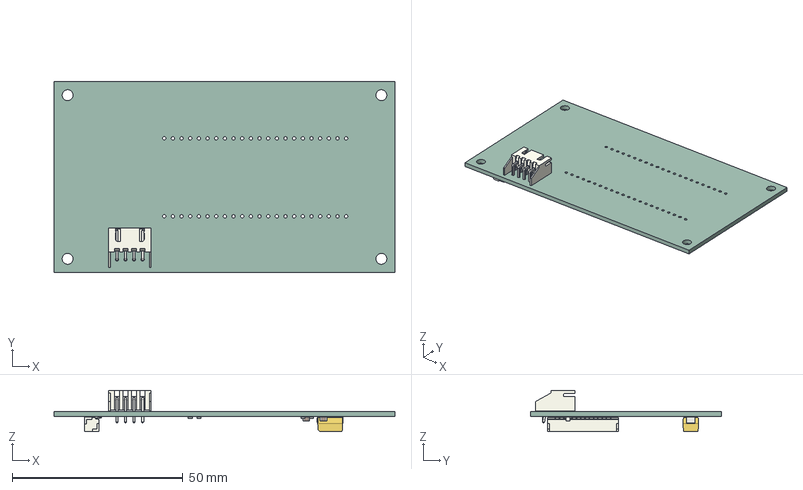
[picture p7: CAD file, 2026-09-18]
fab/sh03-controller.step
100.0 x 56.0 x 12.1 mm
JST_S4B_XH_A
C_0805_2012Metric x 2
CP_EIA_7343_43_Kemet_X
R_0805_2012Metric x 4
JST_BM14B_GHS_TBT
sh03-controller_PCB

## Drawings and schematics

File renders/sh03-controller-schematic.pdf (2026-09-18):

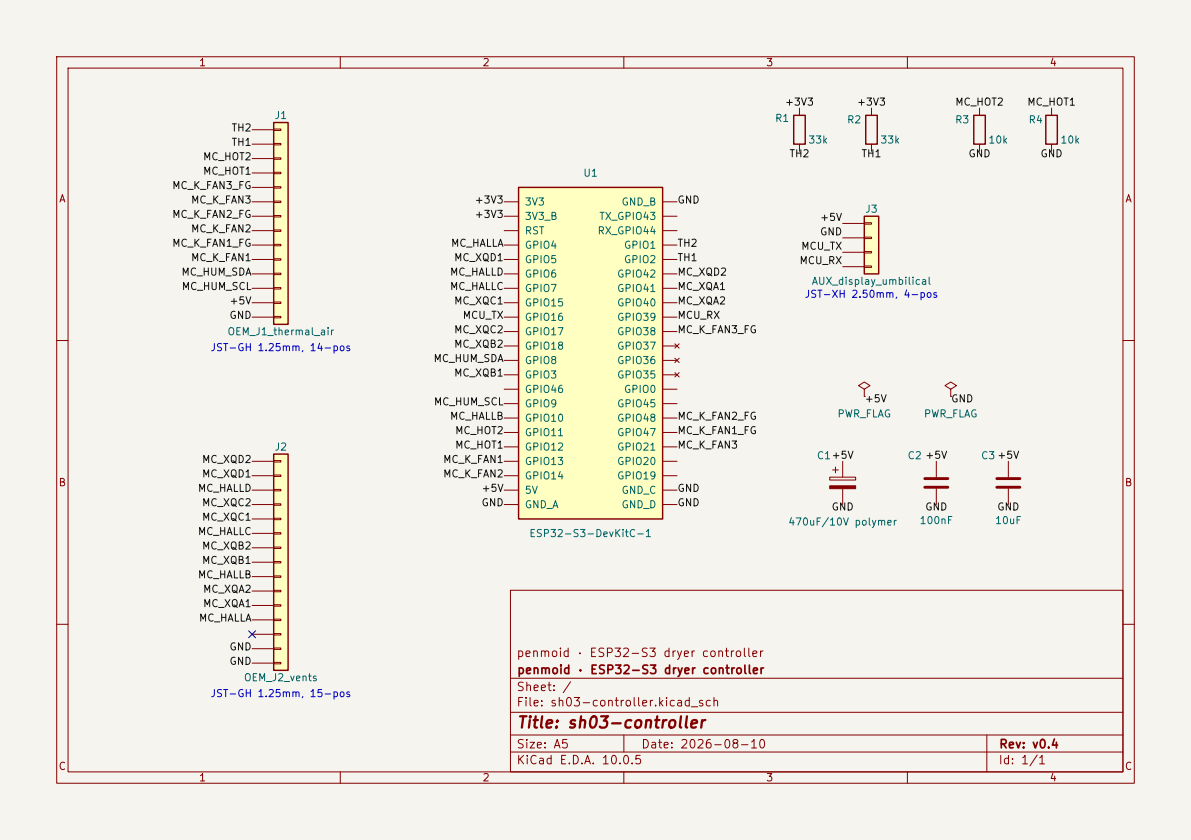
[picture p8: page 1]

Size: A5 | Rev: v0.4 | C Date: 2026-08-10
KiCad E.D.A. 10.0.5 | Id: 1/1

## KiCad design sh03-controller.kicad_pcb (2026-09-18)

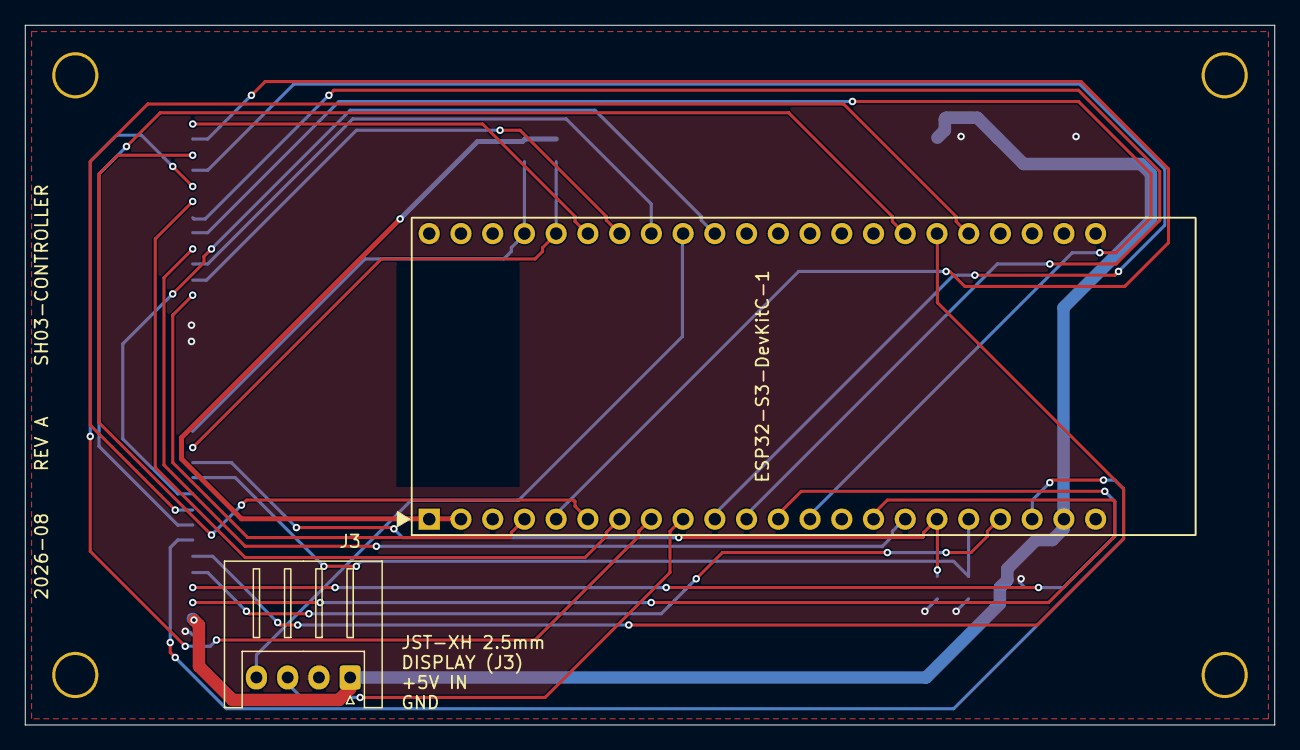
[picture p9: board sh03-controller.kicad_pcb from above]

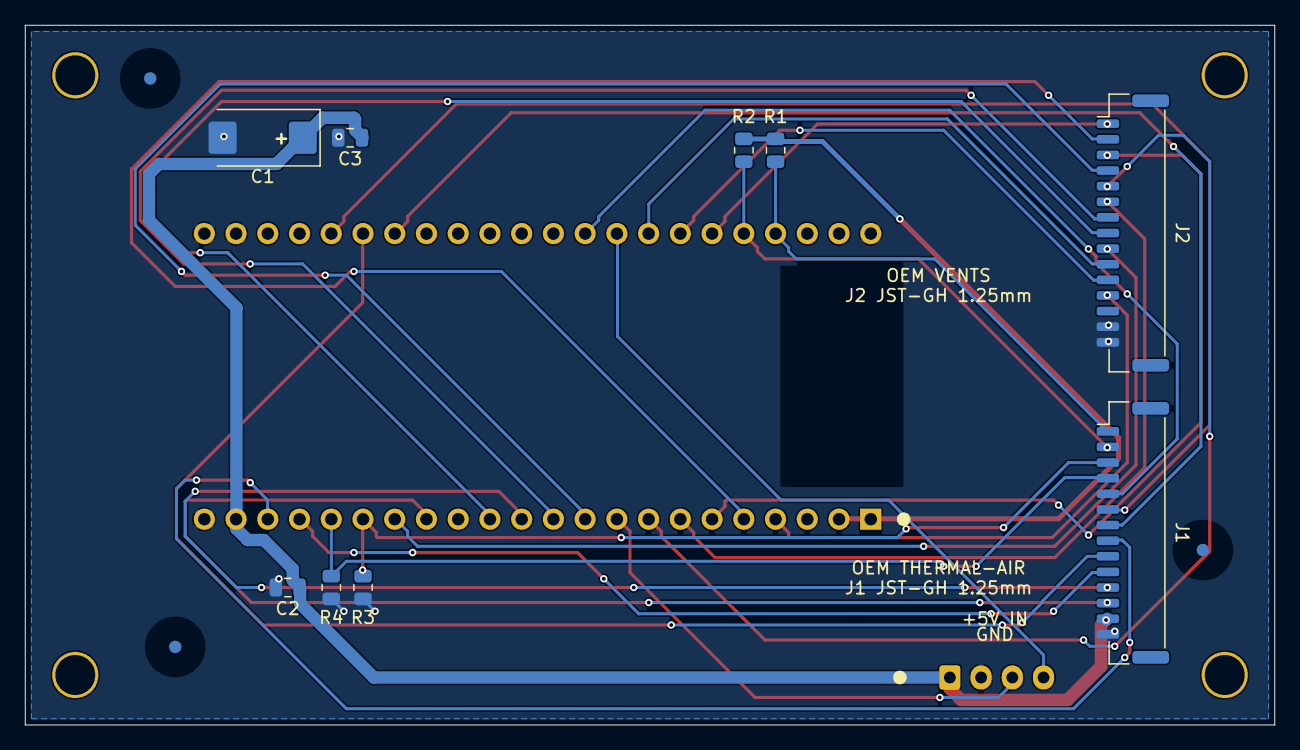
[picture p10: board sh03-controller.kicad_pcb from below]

Board: 2 copper layers, 100.0 x 56.0 mm, 18 parts (12 on the bottom side), 29 nets.

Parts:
C1: 470uF/10V polymer; CP_EIA-7343-43_Kemet-X_HandSolder
C2: 100nF; C_0805_2012Metric
C3: 10uF; C_0805_2012Metric
FID1, FID2, FID3: FIDUCIAL
H1, H2, H3, H4: MountingHole; MountingHole_3.2mm
J1: OEM_J1_thermal_air; JST_GH_BM14B_UNIVERSAL_1x14-1MP_P1.25mm_Vertical
J2: OEM_J2_vents; JST_GH_BM15B_UNIVERSAL_1x15-1MP_P1.25mm_Vertical
J3: AUX_display_umbilical; JST_XH_S4B-XH-A_1x04_P2.50mm_Horizontal
R1, R2: 33k; R_0805_2012Metric
R3, R4: 10k; R_0805_2012Metric
U1: ESP32-S3-DevKitC-1; ESP32-S3-DevKitC-1-Socket

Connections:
/+3V3: R1.1, R2.1, U1.1, U1.2
/+5V: C1.1, C2.1, C3.1, J1.13, J3.1, U1.21
/GND: C1.2, C2.2, C3.2, J1.14, J2.14, J2.15, J3.2, R3.2, R4.2, U1.22, U1.23, U1.43, U1.44
/MCU_RX: J3.4, U1.31
/MCU_TX: J3.3, U1.9
/MC_HALLA: J2.12, U1.4
/MC_HALLB: J2.9, U1.16
/MC_HALLC: J2.6, U1.7
/MC_HALLD: J2.3, U1.6
/MC_HOT1: J1.4, R4.1, U1.18
/MC_HOT2: J1.3, R3.1, U1.17
/MC_HUM_SCL: J1.12, U1.15
/MC_HUM_SDA: J1.11, U1.12
/MC_K_FAN1: J1.10, U1.19
/MC_K_FAN1_FG: J1.9, U1.39
/MC_K_FAN2: J1.8, U1.20
/MC_K_FAN2_FG: J1.7, U1.38
/MC_K_FAN3: J1.6, U1.40
/MC_K_FAN3_FG: J1.5, U1.32
/MC_XQA1: J2.11, U1.29
/MC_XQA2: J2.10, U1.30
/MC_XQB1: J2.8, U1.13
/MC_XQB2: J2.7, U1.11
/MC_XQC1: J2.5, U1.8
/MC_XQC2: J2.4, U1.10
/MC_XQD1: J2.2, U1.5
/MC_XQD2: J2.1, U1.28
/TH1: J1.2, R2.2, U1.27
/TH2: J1.1, R1.2, U1.26

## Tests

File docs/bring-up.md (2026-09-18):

# Bring-up status and checks

The project author has personally validated correct operation of the assembled
Rev-A board in the dryer. The repository contains CAD validation, fabrication
outputs, and continuity-check guidance. Complete these checks before
connecting each new board to a dryer.

## Safety rules

- Never connect USB and the dryer harness at the same time. The DevKitC-1 can
  feed USB power back into the dryer harness.
- Fit J1 to the PCB before powering the dryer. R3 and R4 are mandatory 10k
  pull-downs for the heater lines.
- Keep J2 pin 13 unconnected. It isolates the driver-board 3V3 signal.
- Unplug the dryer, allow the low-voltage rail to discharge, and verify 0 V at
  the +5V rail before changing cables, headers, or the DevKitC-1.

## Before power

1. Inspect every J1/J2 solder joint for bridges, missing parts, and lifted
   leads. Confirm that C1's positive stripe is on the +5V net.
2. Confirm the board is 100 × 56 mm and that the mounting holes accept M3
   hardware. Rev-A mounting holes are plated with a 3.2 mm finished diameter.
3. Confirm J2 is the north connector and J1 is the south connector. Pin 1 is
   at the north end of each connector.
4. Check cable continuity end to end. Require pin 1 to pin 1 through pin N to
   pin N. Reject reversed or cross-wired cables.
5. Check that every cable contact is retained in its housing. Test the
   connector mate before applying force to a clone or genuine JST part.

## Unpowered board checks

Use a DMM with the DevKitC-1 removed.

- Check for no sustained short between +5V and GND. A brief capacitor charge
  response is expected.
- Check +5V continuity between J1.13, J3.1, U1.21, C1 positive, C2.1, and
  C3.1.
- Check GND continuity between J1.14, J2.14, J2.15, J3.2, U1.22, U1.23,
  U1.43, and U1.44.
- Measure about 10k from J1.3 and J1.4 to GND through R3 and R4. An open
  reading means the heater pull-down is missing.
- Check J2.13 for isolation from adjacent pins, +5V, and GND.
- Check every connected connector-to-U1 path against
  [`pad-report.txt`](pad-report.txt) and the GPIO table in
  [`gpio-remap.md`](gpio-remap.md).

## Assembly checks

U1 may use suitable 2×22, 2.54 mm headers or sockets. Direct solder is also a
supported assembly method and is the current build arrangement. Fit the
DevKitC-1 only after checking header alignment and rechecking the +5V/GND
neighbours around U1.21 and U1.22.

## Power-up boundary

Do the first powered test from USB with the dryer harness disconnected. Check
for stable 5 V and 3.3 V rails, 0 V on both heater outputs at boot, and the
expected GPIO map from `docs/gpio-remap.md`. Use a separate bench firmware
configuration if firmware testing is needed. This repository supplies no
firmware.

After USB testing, unplug USB and discharge the board before connecting the
dryer. Keep the dryer disconnected until cable order, J2.13 isolation, C1
polarity, and both 10k heater pull-downs have passed.

The production cutover requires a firmware build using the current PCB map.
Do not apply that map to the earlier perfboard wiring.
